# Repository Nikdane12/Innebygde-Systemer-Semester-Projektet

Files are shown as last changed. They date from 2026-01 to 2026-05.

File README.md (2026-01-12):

# Innebygde-Systemer-Semester-Projektet
## Sjekkliste
1. Complete the plan of record (POR).
2. Complete the preliminary bill of materials (BOM).
3. Complete the final schematic capture and final BOM.
4. Complete the board layout and order all the parts.
5. Complete the assembly.
6. Complete the bring up, troubleshoot, and final test.
7. Complete the documentation
## POR
- [ ] Visualiser hele prosjeketet før det startes
- [ ] Risikovurdering og risikobegrensing
- [ ] Overordnet beskrivelse av prosjektet, og hva som skal fungere
- [ ] POR er et levende dokument som oppdateres når det kan.
- [ ] Tenk på hva som i verste fall kan skje for hvert steg.
- [ ] Unngå feature creep i denne fasen *
- [ ] Estimer det du kan: lab budsjett for strøm pris og leveringstider
- [ ] BOM for de mest kritiske komponentene
- [ ] Gjør en risikoanalyse, og lag plan B-C osv. For potensielle problemer.
## Prosjekt Idèer
- [ ] Spill som bruker ulike sensorer
- [x] Temperatur og fukt-regulert brøddeigboks
- [ ] Drinkmikser
- [ ] Batteridreven bakkestasjon
- [ ] IR-fjernkontroll med vinkelstyring
- [ ] UI for underviser-student-kommunikasjon
- [x] Alternativ navigasjonsmetode for droner
- [ ] Tilgangssystem til dør
- [x] Utskytningsrampe for fixed-wing-drone
- [ ] Plantevannesystem
- [ ] Styring til kaffemaskin
- [ ] Vannkraftverk-modell
- [x] Kamera som følger et objekt
- [x] Globalt posisjoneringssystem med teleskop
- [x] Arm drink dispenser
- [x] Self-leveling table
- [ ] auto solder dispenser

kamera
uv detektor
supersonic sensor
predefined
    vekt/trykk sensor
        mål drikke vekt
    magnetsensor
    lyssensor

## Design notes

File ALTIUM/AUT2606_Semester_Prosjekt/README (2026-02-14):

# README – Kretskort for robotarm (væskefylling)

## 1. Kort beskrivelse
Dette kretskortet er en del av et system for en **robotarm som kan navigere til predefinerte posisjoner og fylle glass med væske**.  
Kortet brukes som grensesnitt mellom Raspberry Pi, servoer, pumpe og sensorer, og muliggjør styring samt innhenting av måledata.

---

## 2. Systemfunksjon
Systemet skal:
- Styre flere servoer synkronisert
- Styre en pumpe som leverer væske i kontrollerte mengder
- Måle vekt ved hjelp av loadcell for å avgjøre når et glass trenger påfyll
- Kommunisere med Raspberry Pi via I²C og digitale signaler

---

## 3. Grunnlinjefunksjonalitet
- Robotarmen kan bevege seg til en forhåndsdefinert posisjon  
- Servoene beveger seg koordinert og jevnt  
- Pumpen leverer en repeterbar mengde væske  
- Systemet kan avgjøre når et glass trenger mer væske basert på vekt  

### Ønsket ekstrafunksjonalitet
- Kamera for økt presisjon (ikke implementert på dette kretskortet)

---

## 4. Kretskortets rolle
Kretskortet fungerer som et **styre- og grensesnittkort** mellom Raspberry Pi og følgende moduler:
- PWM-servo-driver (PCA9685)
- Vektsensor-forsterker (HX711)
- Ekstern pumpe-driver (TC1508-modul)

---

## 5. Komponenter (BOM – oversikt)
Viktige komponenter på kretskortet:
- **HX711** – ADC/forsterker for loadcell
- **Loadcell 1 kg** – Vektmåling
- **Servo-tilkoblinger** – 3 kraftservoer + 1 mikroservo
- **Pumpe-tilkobling** – Styring via ekstern H-bridge

### Standard / No BOM

- HX711
- PCA9685
- Loadcells
- Servo motorer
- Pumpe

---

## 6. Multiplisitet
- Det bestilles 2 kort (Hoved og HX711)
- Alle komponentantall i BOM er oppgitt

---

## 7. PCB- og mekaniske begrensninger
- Maks størrelse: **60 mm × 30 mm**
- 2-lags PCB
- Kompatibel med **JLCPCB design rules**
- Hovedsakelig SMD-komponenter på **Top Layer**
- Testpunkter, tydelig silketrykk og innfesting er inkludert der det er relevant

---

## 8. Bring-up (kortversjon)
1. Verifiser I²C-kommunikasjon mellom Raspberry Pi og PCA9685  
2. Test styring av én servo  
3. Test HX711 med last på loadcell  
4. Test start/stopp av pumpe  
5. Integrer vektmåling og pumpe i lukket sløyfe  

---

## 9. Designerinformasjon
**Navn:** Nikolai A. Dickens  
**Kontakt:** nidic4105@uit.no

**Navn:** Olav A. Sødal  
**Kontakt:** olsod5888@uit.no

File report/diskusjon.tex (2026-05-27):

\section{Diskusjon}
Resultatene viser at systemet fungerte etter hensikten. Armen klarte å registrere når en kopp kom under den gitte terskelverdien, bevege seg til riktig posisjon og fylle koppen til eller over målnivået.

Som nevnt i resultatene var det et avvik under fylleprosessen. Avviket vurderes som akseptabelt for fylling av et glass, men kan reduseres ved å forbedre målingene fra loadcellene. En feilkilde her var drift i verdiene fra HX711, der avlesningene endret seg gradvis over tid uten endring i vekt. Denne driften er en av årsakene til det varierende avviket etter fylling. Effekten av driften kan reduseres ved jevnlig nullstilling (tare), filtrering av avlesningene gjennom median- eller gjennomsnittsmodus, og bedre skjerming av kabler for å redusere støy.

At reguleringen fungerte tilfredsstillende med så lite tuning av PID-verdiene tyder på at de valgte standardverdiene var godt egnet for systemet.
 
Likevel, selv om systemet nådde hensikten, var det noen svakheter og feilkilder i dette systemet.

En mekanisk svakhet var at de interne tannhjulene i servoene var laget av plast. Som beskrevet i resultatene førte dette til at servoen på skulderen sluttet å rotere etter høyt stress. Årsaken er at servoene som ble brukt ikke er dimensjonert for de kreftene armen utsettes for, noe som er en kjent svakhet ved billigere servoer med plastgir. Bytte til en servomotor med metallgir løste problemet, og er også å foretrekke på lengre sikt for å sikre armens presisjon og levetid. 

Problemet med ''brownout'' på RPi-en skyldtes ikke selve strømforsyningen, men ledningene mellom strømforsyningen og hoved-PCB-en. Opprinnelig var det brukt tynne kabler som var ''daisychained'' videre til kortet, noe som ga for stort spenningsfall ved høyt strømtrekk, særlig når servoene og pumpen var aktive samtidig. En ''brownout'' kan føre til ustabil oppførsel eller at Pi-en restarter. Problemet ble løst ved å bytte til kraftigere kabler koblet direkte fra strømforsyningen til hoved-PCB-en. Dette reduserte spenningsfallet, og strømforsyningen leverte deretter stabil spenning også under høy belastning.

De tre feilene som ble oppdaget på hoved-IO-kortet lot seg fikse med loddebroer og kabling, og bør rettes opp i designet i en eventuell ny revisjon av kortet.

Noen tekniske valg ble gjort under dette prosjektet. Det ble valgt å bruke en egen PSU i stedet for en laboratorie strømforsyningen. Dette var fordi at systemet hadde behov for en strømforsyning som kunne levere nok amper til alle komponentene samtidig (kan se i POR-vedlegget). Det som er beskrevet over viste det seg likevel at strømforsyningen ikke var godt nok dimensjonert noe som førte til ''brownout'' ved høyt strømtrekk. Varselmeldingen på RPi-en om at det var for lite strøm kan være fordi PSU-en leverte 4,9V i stedet for 5V eller helst 5,1 V til RPi-en. Dette valget bør derfor revurderes med tanke på en annen PSU.

For å styre pumpen med PWM-signaler ble det valgt å bruke en ekstern modul (L298N) i stedet for å integrere H-broen direkte på PCB-en. Dette var fordi det begynte å bli lite plass igjen på PCB-en til alle funksjonene, og for å redusere risikoen for at hovedfunksjonen: å styre pumpen med PWM, ikke skulle fungere. Ved å legge pumpestyringen i en egen modul ble designet enklere og sjansen for feil på selve kortet redusert.

Samlet sett fungerte systemet etter hensikten. Pumpestyringen med PID-regulering ga presis fylling med kun et lite avvik, og robotarmen klarte å bevege seg mellom de forhåndsdefinerte posisjonene som planlagt. Svakhetene som ble avdekket lot seg alle utbedre underveis, og påvirket ikke det endelige resultatet.

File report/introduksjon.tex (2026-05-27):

\section{Introduksjon}
I dette semesterprosjektet har vi laget en automatisk refill-arm, en robotarm som fyller glass med væske når en vektsensor registrerer at de er tomme. Prosjektet er gjennomført i emnet AUT-2606 ved Institutt for Automasjon og Prosessteknologi, og målet har vært å vise og videreutvikle vår kunnskap innen mekanismer, PCB-design og programmering.

Rapporten gir først en gjennomgang av det teoretiske grunnlaget for komponentene og metodene som er brukt, blant annet regulering og invers kinematikk. Deretter beskrives metodikken bak design av kretsen, lodding og programvaren, før vi presenterer og diskuterer resultatene fra det ferdige systemet.

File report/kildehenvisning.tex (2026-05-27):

\section{Kildehenvisning}
\begin{hangparas}{0.5in}{1}
Cults3D. (u.å.). \emph{Arduino based robot arm – HowToMechatronics} [3D-modell]. Hentet 26. mai 2026 fra \url{https://cults3d.com/en/3d-model/various/arduino-based-robot-arm-howtomechatronics}

Handson Technology. (u.å.). \emph{L298N dual H-bridge motor driver} [Datablad]. Hentet 26. mai 2026 fra \url{https://www.handsontec.com/dataspecs/L298N\%20Motor\%20Driver.pdf}

NXP Semiconductors. (2015). \emph{PCA9685: 16-channel, 12-bit PWM Fm+ I\textsuperscript{2}C-bus LED controller} [Datablad]. \url{https://www.nxp.com/docs/en/data-sheet/PCA9685.pdf}

SparkFun Electronics. (u.å.). \emph{HX711: 24-bit analog-to-digital converter (ADC) for weigh scales} [Datablad]. Hentet 26. mai 2026 fra \url{https://cdn.sparkfun.com/datasheets/Sensors/ForceFlex/hx711_english.pdf}

Wikipedia. (u.å.). \emph{Inverse kinematics}. Hentet 26. mai 2026 fra \url{https://en.wikipedia.org/wiki/Inverse_kinematics}

[Forfatter, A. A.]. (årstall). \emph{Inverse kinematics} [Figur]. ResearchGate. \url{https://www.researchgate.net/figure/Inverse-kinematics-problem-of-3-DOF-robot-arm-in-2D-plane-a-Three-joints-and-an_fig3_46401997}

[Forfatter, A. A.]. (årstall). \emph{Inverse kinematics}. ResearchGate. \url{https://www.researchgate.net/publication/274164740_Inverse_Kinematics}
\end{hangparas}

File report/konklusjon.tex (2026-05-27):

\section{Konklusjon}
I dette prosjektet ble det laget en automatisk refill arm som fyller glass med væske når en vektsensor registrerer at de er tomme. Systemet ble bygget opp av en Raspberry Pi med egendesignede PCB-er, 3D-printede deler og øvrige elektronikkomponenter, og programvare som håndterer PID-regulering og invers kinematikk.

Prosjektet nådde hovedmålet sitt. Den ferdige armen klarte å registrere tomme kopper og bevege seg til riktig posisjon og fylle dem med et avvik på omtrent 10g som blir vurdert som tilstrekkelig presist for formålet. 

For videre arbeid bør de tre feilene som ble oppdaget under testing: manglende jording av OE-pinnen på PCA9685, ombyttede I2C-pinner, og manglende styringspinne for pumpen, rettes direkte i designet i en ny revisjon av kortet, slik at de ikke lenger må utbedres med loddebroer og kabling. Videre bør servoene byttes ut med motorer med metallgir i stedet for plastgir for å gjøre armen mer robust. På lengre sikt kan systemet integreres med trådløs kommunikasjon mellom lastcellene og RPi-en, noe som ville gjort oppsettet mer fleksibelt og redusert behovet for kabling.

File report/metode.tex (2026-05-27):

\section{Metode}
\begin{figure}[H]
    \centering
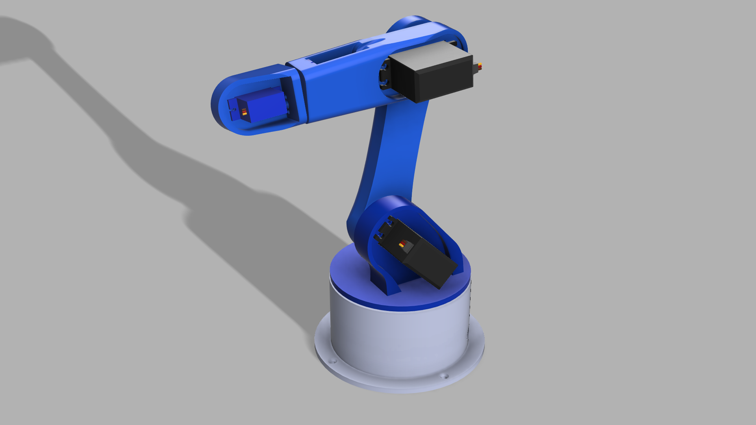
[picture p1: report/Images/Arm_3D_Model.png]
    
    \caption{3D model av robot arm}
    \label{fig:3D_arm}
\end{figure}

\subsection{Testing før mottatt PCB}
Siden produksjon og levering av PCB-ene tok tid, var det viktig å verifisere at de sentrale komponentene og kommunikasjonsprotokollene fungerte før kortene kom i posten. Raspberry Pi-en ble stilt til rådighet av universitetet tidlig i prosjektet, og vi brukte derfor denne til å teste de ulike delene av systemet hver for seg på forhånd.

Først testet vi I2C-kommunikasjonen, ettersom denne er avgjørende for styringen av servomotorene. Ved hjelp av en frittstående PCA9685-modul koblet til Raspberry Pi-en kunne vi bekrefte at Pi-en oppdaget enheten på I2C-bussen, og at vi klarte å generere stabile PWM-signaler ut fra modulen. På denne måten fikk vi verifisert både selve I2C-oppsettet og at vi kunne styre en servomotor via PCA9685 før dette ble integrert på vårt eget kort.

\subsection{Kretsen}
Vi tok hva vi hadde i POR-en for å finne ut hvilke funksjoner som var nødvendige, og hvilke som kunne inkluderes om vi hadde plass til det. Vi fant ut at kortet skal gi ut fem PWM-signaler, tre knapper, muligheten strømtilførsel uten USB-C, fire ledige pins for I2C-kommunikasjon, samt tre HX711-brikker for loadcells.

\input{BOM}

Ved bruk av Raspberry Pi-en ble hovedprosesseringen og styringen forenklet. Pi-en ga en fornuftig måte å kommunisere med de andre komponentene på, via I2C, bit-banging og innlesing gjennom GPIO-pinnene.

Først fant vi ut hvordan PWM-utgangene skulle styres. PWM-signalet genereres ikke direkte av Raspberry Pi-en, men av en PCA9685 PWM-driver som Pi-en kommuniserer med over I2C. Figur \ref{fig:transistor} viser hvordan transistoren brukes. Signalet fra PCA chippen føres til PWM inngangen i kretsen, der strømmen går gjennom en motstand som begrenser basestrømmen til transistoren. Transistoren er en NPN BJT som opererer i en «common-emitter»-konfigurasjon, det vil si at emitteren er felles for inngangen og utgangen. Deretter er collector-pinnen koblet til en pull-up-motstand.

Når PWM-signalet er høyt, driver basestrømmen transistoren til saturation. Collectoren blir da trukket ned mot GND, og utgangen settes lav. Når PWM-signalet er lavt, går det ingen strøm til basen, og transistoren er «av». Da går det ingen strøm gjennom pull-up-motstanden, og utgangen trekkes høy til 5V.

\begin{figure}[H]
    \centering
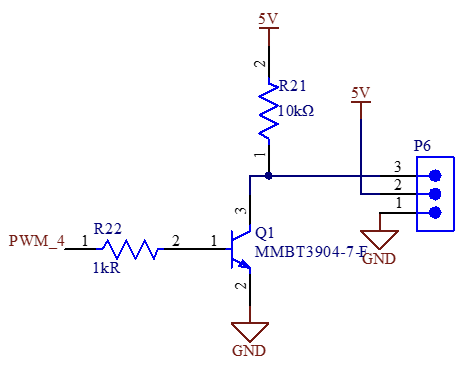
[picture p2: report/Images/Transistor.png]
    
    \caption{Transistor oppsett}
    \label{fig:transistor}
\end{figure}

Hx711 kretsen var en ukjent komponent som krevet mye forskning. Hoved krets design/oppsett kom fra en produsent som leverer ferdig bygget Hx711 PCB-er. 

\subsection{Beste praksis for PCB-design}
\textbf{Avkoblingskondensatorer:} Hver aktive komponent ble utstyrt med avkoblingskondensatorer plassert så nær forsyningspinnene som mulig. PCA9685 og HX711-brikkene har dedikerte 100nF keramiske kondensatorer for å filtrere ut høyfrekvent støy, samt større 10 µF elektrolytt-/keramiske kondensatorer for å stabilisere forsyningsspenningen ved raske lastendringer. 

\textbf{Jordplan:} Kortet ble lagt ut med et sammenhengende jordplan (kobberfyll for GND). Et jordplan gir lav impedans tilbake til forsyningen og korte returbaner for signalstrømmene, noe som reduserer støy og gir mer stabile referansenivåer. Dette er særlig fordelaktig for de analoge målesignalene fra lastcellene, der et stabilt jordreferansenivå er avgjørende for nøyaktige avlesninger.

\textbf{Sporbredde for forsyning:} Spor som fører forsyningsstrøm (5V og 12V) ble tegnet merkbart bredere enn signalspor. Bredere spor har lavere resistans, noe som reduserer spenningsfallet og varmeutviklingen ved høyt strømtrekk. Dette er viktig i et system der servoer og pumpe kan trekke betydelig strøm samtidig.

\textbf{Separasjon av analoge signaler:} De analoge linjene fra lastcellene ble bevisst holdt adskilt fra PWM- og effektspor. Ved å unngå at følsomme målesignaler rutes parallelt med eller krysser støyende spor, reduseres innkobling av støy på HX711-avlesningene.

\subsection{Lodding}
    \hl{plassering av komponenter\\
    varmeovn\\
    through-hole deler}
\subsubsection{Enderinger}
    \hl{SDA pin\\
    floating ground\\
    pumpe int pin}

\subsection{Programmering}
\subsubsection{PCA9685}
PCA9685 chippen kommuniserer gjennom I2C, og siden PCA9685 er en ganske populær chip som blir brukt for å klare å styre flere servo motorer samtidig så eksisterte det allerede et bibliotek på python for denne chippen.

\subsubsection{HX711}
HX711 bruker sin egen type protokoll for kommunikasjon. Hvor RPi-en sender en 24 klokke pulser og for hver puls sender chippen ut et bit. Fra dette kan vi få data ut fra loadcellene som kan tolkes til vekt.

\subsection{main.py}
Programmet består av tre hoveddeler: import av nødvendige biblioteker, 
definisjon av matematiske funksjoner, og bygging av grafisk brukergrensesnitt (GUI).

\begin{figure}[H]
    \centering
    \includesvg[width=.75\linewidth]{Images/PackageDiagram.svg}
    \caption{Package Diagram}
    \label{fig:PackageDiagram}
\end{figure}

\subsubsection{Importerte biblioteker}
Følgende biblioteker blir importert:
\begin{itemize}
    \item \texttt{tkinter} — brukes til å lage det grafiske brukergrensesnittet (GUI)
    \item \texttt{time} — brukes til tidsmåling i PID-regulatoren
    \item \texttt{subprocess} — brukes til å starte eksterne prosesser, 
          som benchmark-programmet
    \item \texttt{math} — brukes til trigonometriske beregninger i invers kinematikk
    \item \texttt{ADAfruit} — 
    \item \texttt{hx711} — egen modul for avlesning av vektceller
\end{itemize}

\subsubsection{Tilstand}
Programmet bruker en global tilstandsmaskin med tre tilstander for fylleprosessen:
\begin{itemize}
    \item \texttt{idle} — systemet venter og overvåker vektcellene
    \item \texttt{moving} — armen beveger seg mot riktig glass
    \item \texttt{filling} — pumpen er aktiv og PID-regulatoren styrer fyllingen
\end{itemize}

\begin{figure}[H]
    \centering
    \includesvg[width=.75\linewidth]{Images/Tilstandsdiagram.svg}
    \caption{Tilstands Diagram}
    \label{fig:Tilstandsdiagram}
\end{figure}

\subsubsection{Invers kinematikk}
Funksjonen \texttt{solve\_ik()} beregner leddvinklene som kreves for å 
plassere endeffektoren i en gitt posisjon $(x, y, z)$ med ønsket 
orientasjon $\phi$.

\subsubsection{PID-regulator}
Funksjonen \texttt{pid\_control()} implementerer den diskrete PID-regulatoren. Regulatoren styrer pumpeeffekten 
basert på differansen mellom ønsket fyllingsnivå og målt vekt. 
Standardverdiene er satt til:
\begin{itemize}
    \item $K_p = 0.5$
    \item $K_i = 0.1$
    \item $K_d = 0.05$
\end{itemize}
Disse kan justeres direkte i GUI-et under kjøring.

\subsubsection{Fylleprosess}
Fylleprosessen styres av tre funksjoner:
\begin{itemize}
    \item \texttt{start\_fill()} — flytter armen til riktig glass og starter pumpen
    \item \texttt{begin\_pump()} — aktiverer pumpen og nullstiller PID-tilstanden
    \item \texttt{pid\_fill\_loop()} — kjører PID-regulatoren i en løkke med 
          \texttt{PID\_POLL\_MS} intervall (standard 200~ms) til målvekten er nådd
    \item \texttt{stop\_pump()} — slår av pumpen og returnerer til \texttt{idle}
\end{itemize}

Hvis vektcellen leser en negativ verdi under fylling tolkes dette som at 
glasset er løftet bort, og fyllingen avbrytes automatisk.

\subsubsection{Hovedløkke}
Funksjonen \texttt{main\_loop()} kjøres hvert 500~ms og overvåker alle 
tre vektcellene. Hvis systemet er aktivert og et glass er under 
terskelverdien \texttt{FILL\_THRESHOLD\_G} (standard 150~g), 
startes fylleprosessen automatisk for det aktuelle glasset.

\subsubsection{GUI}
GUI-et er bygget med \texttt{tkinter} og inneholder følgende seksjoner:
\begin{itemize}
    \item \textbf{Joint Control} — glidere for manuell styring av hvert ledd 
          (midje, skulder, albue, wrist) samt pumpe
    \item \textbf{Inverse Kinematics} — inntastingsfelt for målposisjon 
          $(x, y, z, \phi)$ og geometriparametere
    \item \textbf{Saved Positions} — lagring og avspilling av inntil 3 posisjoner med jevn interpolasjon
    \item \textbf{Load Cell} — sanntidsavlesning av alle tre vektceller med valg mellom live- og medianmodus
    \item \textbf{Tare og Kalibrering} — Kalibrering av innsamlet data fra loadcells og nullstillingsfunksjon
    \item \textbf{Fill Settings} — innstilling av terskel- og målvekt for fylling
    \item \textbf{Water Level} — fremdriftsindikatorer som viser fyllingsnivå 
          for hvert glass
    \item \textbf{PID Controller} — felt for $K_p$, $K_i$ og $K_d$ 
          med knapp for å anvende nye verdier under kjøring
\end{itemize}

\subsubsection{Avslutning}
Når programmet avsluttes frigjøres alle ressurser:
\begin{itemize}
    \item Vektcellene \texttt{sensor1}, \texttt{sensor2}, \texttt{sensor3} lukkes
    \item SPI-klokken \texttt{hx711.sck} lukkes
    \item Pumpe-GPIO-porten \texttt{pump\_fwd} lukkes
    \item I2C-bussen \texttt{i2c.bus} lukkes
\end{itemize}

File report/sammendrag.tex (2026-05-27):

\section{Sammendrag}
Vi har satt oss fore å lage en maskin som viser vår kunnskap om mekanismer, PCB-design og programmering. Hovedsystemet er satt sammen av en Raspberry Pi, tilpassede PCB-er, 3D-printede deler og andre elektronikkomponenter. Vi har tilpasset alle komponenter slik at de passer sammen, og designet PCB-ene for å levere den nødvendige funksjonaliteten: PWM-utganger, I/O-knapper, HX711 loadcell-brikker og dedikerte I2C-tilkoblinger. Programvaren gir PID-regulering, IK-posisjonering og tilstandsmaskiner. Til slutt har vi bygget, testet, feilrettet og ferdigstilt en robotarm som fyller glass når vektsensoren registrerer at de er tomme. Vi har dermed nådd målet for semesterprosjektet.

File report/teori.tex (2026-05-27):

\section{Teori}

\subsection{Raspberry Pi}
Raspberry Pi er datamaskinen i dette prosjektet. Det ble valgt for å bruke RPi fordi det er en kraftig datamaskin som kan kjøre programmer raskt, samtidig som den har GPIO-pinner som gir mulighet for tilkobling av ekstern tilkobling. RPi-en kan også kobles til GitHub, noe som gir en raskere og enklere arbeidsflyt. I tillegg støtter RPi-en alle kommunikasjonsprotokollene vi trengte i prosjektet, blant annet I2C og bit bang.

\subsection{PCA9685}
For å kunne kontrollere flere servomotorer samtidig ved bruk av RPi-en, brukte man chippen PCA9685. Denne gjør det mulig å styre opptil 16 servomotorer via I2C, med presise og stabile PWM signaler enn hva RPi-en kan gi.

\subsubsection{I2C}
I2C er kommunikasjon protokollen som blir brukt i PCA9685. I2C blir vanligvis brukt å koble mellom mikrokontrollere og sensorer, minnebrikker og andre enheter. 

Buss strukturen til I2C er en synkron toveis kommunikasjonsbuss som kun benytter av to ledere: SDA (Serial Data) som er linjen som overfører data og SCL (Serial Clock) som er klokken som synkroniserer dataoverføringen laget av master enheten.

Kommunikasjonen bruker master og slave prinspit. Det er en master enhet (vanligvis en mikrokontoler eller RPi i dette prosjektet) som styrer klokkesignalet og initialerer komunaksjonen. Og slave enheter svarer når kun de er addresert. Man kan tenke seg slikk at master enheten er posten som levere ut inviasjonen og slaven kan bare svare hvis de har fått invitasjoner. Hver slave har en unik addresse som er regel på 7 bit. Det gir i teori opp til 128 enheter på samme buss linje.

\colorbox{yellow}{placeholder}
Data overføring skjer slik ut. 
Masteren sender en startbetingelse (SDA går lav mens SCL er høy).
Masteren sender slavens 7-bits adresse fulgt av en lese-/skrivebit (R/ som angir overføringsretning.
Den adresserte slaven svarer med et ACK-bit (acknowledge) for å bekrefte at den er tilstede.
Data overføres byte for byte, hvor hver byte etterfølges av et ACK- eller NACK-bit fra mottakeren.
Masteren avslutter med en stoppbetingelse (SDA går høy mens SCL er høy).

\subsection{HX711}
For å måle vekten på glassene brukte vi chippen HX711. Denne chippen leser av analoge signaler fra en lastcelle og konverterer dem til digitale data. HX711 er en 24 bits analog til digital omformer (ADC) spesielt beregnet for lastceller. Chippen kommuniserer med RPi-en via sin egen serielle protokoll basert på bit-banging. Siden hver HX711 kun kan lese fra en lastcelle, måtte vi ta i bruk tre chipper for å kunne lese av tre lastceller.

\subsubsection{Bit bang}

\subsection{Dual H-Brigde L298N module}
Modulen bruker både 5V og 12V. Den mottar et PWM-signal og har i tillegg en «HIGH-pin» og en «LOW-pin» som bestemmer hvilken retning pumpen går. Bytter man om på disse to pinnene, snur pumpe retningen.

Modulen er en dobbel bidireksjonell H-bro. Det betyr at den kan styre to DC-motorer samtidig uavhengig av hverandre. En H-bro er en standard-krets av fire transistorer satt sammen i en form som ligner på bokstaven H, hvor motoren er plassert i midten. Med å aktivere diagonalt motsatte transistorer kan strømmen gå gjennom motoren, og å aktivere motsatte transistorer vil de gå motsatt vei.

PWM-signalet brukes til å styre hastigheten på motoren. PWM-en veksler raskt mellom «HIGH» og «LOW», og forholdet mellom "HIGH" tid og "LOW" tid kalles «duty cycle». En høy duty cycle gir motoren høyere hastighet, mens en lav duty cycle gir lavere hastighet.

\subsection{Regulering}
For å fylle glasset og sikre at det blir fylt opp uten søl, brukes en form for regulering. En regulator sin oppgave er å styre et system slik at den målte $y(t)$ følger en ønsket referanseverdi så presist som mulig. I dette prosjektet styres pumpen ut fra hvor mye væske som skal være i glasset, slik at fyllingen stoppes på riktig tidspunkt.

\begin{figure}[H]
    \centering
    \includesvg[width=1\linewidth]{Images/PID.svg}
    \caption{PID sløyfe}
    \label{fig:PID_diagram}
\end{figure}

Reguleringen er bygget opp som en \emph{lukket sløyfe}. Det innebærer at den målte $y(t)$ kontinuerlig sammenlignes med referanseverdien, og at differansen mellom dem brukes til å bestemme pådraget. Feilsignalet er definert som differansen mellom referanseverdien $y_0(t)$ og målte ut verdien $y(t)$:
\begin{equation}
    e(t) = y_0(t) - y(t)
\end{equation}

Uten PID følger kontrolleren en på/av-logikk:
\begin{equation}
    u(t) = \begin{cases} 1 & \text{hvis } e(t) > 0 \\ 0 & \text{hvis } e(t) \leq 0 \end{cases}
\end{equation}

For å oppnå en jevnere og mer presis styring brukes en PID regulator. PID regulatoren består av: et proporsjonalt ledd (P), et integrasjoins ledd (I) og et deriverende ledd (D). 

Og under er $K_p$, $K_i$ og $K_d$ forsterkningskonstantene for henholdsvis proporsjonal, integral og derivasjons leddet. Disse må tunes inn for å gi ønsket oppførsel, der målet er en rask respons med lite oversving og liten stasjonær feil og unngå oscillasjon.
\begin{equation}
    u(t) = K_p \cdot e(t) + K_i \int_0^t e(\tau)\,d\tau + K_d \frac{de(t)}{dt}
\end{equation}

Den diskrete formelen som brukes i koden er:
\begin{equation}
    u[k] = K_p \cdot e[k] + K_i \sum_{j=0}^{k} e[j] \cdot \Delta t + K_d \frac{e[k]-e[k-1]}{\Delta t}
\end{equation}

Integralleddet er her tilnærmet med en Riemann sum, der feilen i hvert tidssteg multipliseres med $\Delta t$ og summeres opp. Derivasjonsleddet er tilnærmet med baklengs differanse (finite difference), altså endringen i feilsignalet fra forrige til nåværende tidssteg delt på $\Delta t$. Disse tilnærmingene blir mer nøyaktige jo mindre $\Delta t$ er.

\subsection{Invers kinematikk}
For å styre bevegelsen til robotarmen brukte vi en forenklet versjon av invers kinematikk. Vi valgte invers kinematikk fremfor fremoverkinematikk fordi fremoverkinematikk beregner endepunktet ut fra kjente leddvinkler, mens invers kinematikk gjør det motsatte den beregner nødvendige leddvinkler for å oppnå en ønsket endeposisjon. Robotarmens geometri er illustrert i figur \ref{fig:3dof}.

\begin{figure}[H]
    \centering
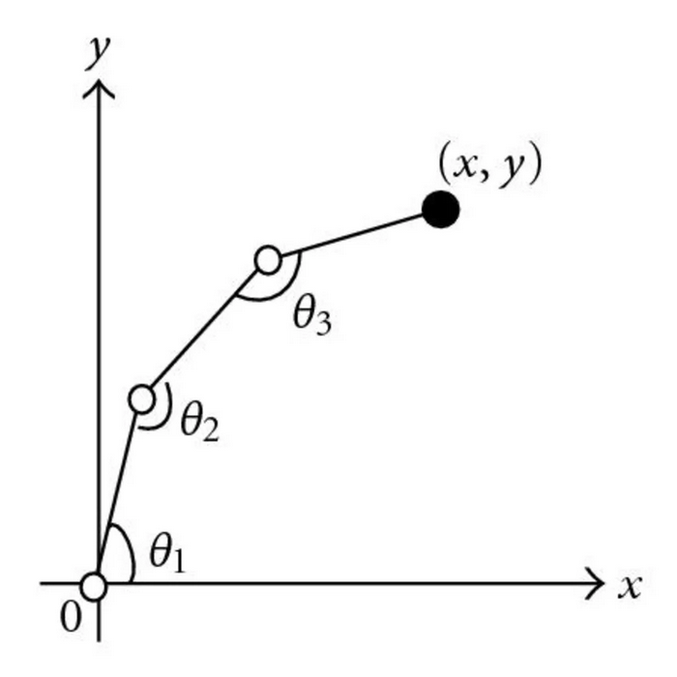
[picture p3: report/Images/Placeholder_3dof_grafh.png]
    
    \caption{Diagram over robotarmens geometri med tre frihetsgrader.}
    \label{fig:3dof}
\end{figure}

Vi definerer håndleddspunktet $(x_w, y_w)$ ved å trekke fra bidraget fra det siste leddet med lengde $L_3$:
\begin{align}
    x_w &= x - L_3 \cos(\varphi) \\
    y_w &= y - L_3 \sin(\varphi)
\end{align}
Vinkelen $\theta_2$ finnes ved hjelp av cosinussetningen:
\begin{align}
    \cos(\theta_2) &= \frac{x_w^2 + y_w^2 - L_1^2 - L_2^2}{2 L_1 L_2} \\
    \theta_2 &= \text{atan2}\!\left(\pm\sqrt{1 - \cos^2(\theta_2)},\ \cos(\theta_2)\right)
\end{align}
Deretter beregnes $\theta_1$ og $\theta_3$:
\begin{align}
    \theta_1 &= \text{atan2}(y_w,\ x_w) - \text{atan2}(L_2 \sin(\theta_2),\ L_1 + L_2 \cos(\theta_2)) \\
    \theta_3 &= \varphi - \theta_1 - \theta_2
\end{align}

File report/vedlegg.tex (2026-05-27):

\section{Vedlegg}

\begin{figure}[H]
    \centering
    \includesvg[width=.75\linewidth]{Images/DeploymentDiagram.svg}
    \caption{Deployment Diagram}
    \label{fig:DeploymentDiagram}
\end{figure}

\begin{figure}[H]
    \centering
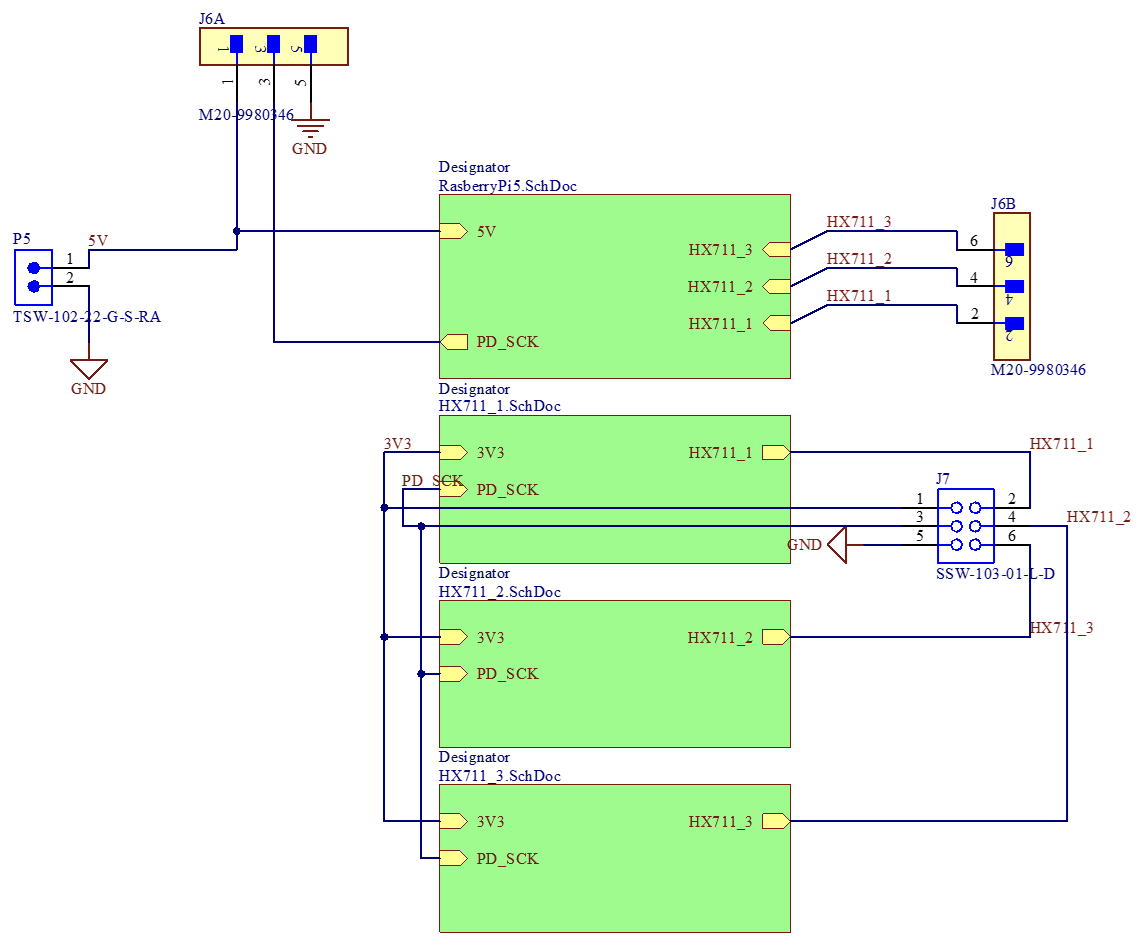
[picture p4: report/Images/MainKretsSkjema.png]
    
    \caption{Hoved kretskjema der alle individe komponenter ble satt sammen.}
    \label{fig:hovedkrets}
\end{figure}

\begin{figure}[H]
    \centering
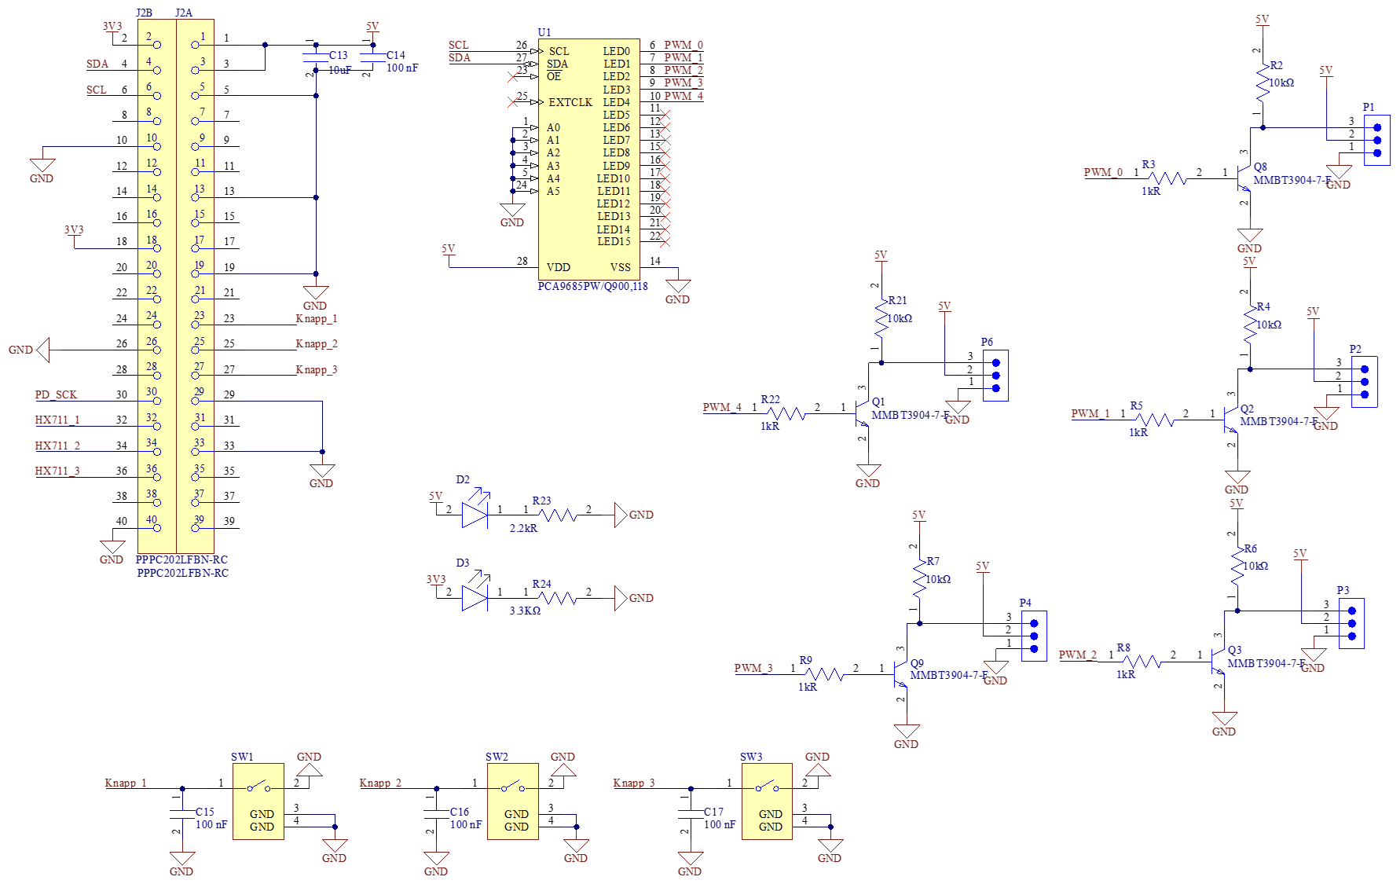
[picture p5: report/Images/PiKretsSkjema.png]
    
    \caption{Pi interface som inkludere PCA9685, PWM switchers, og knapper}
    \label{fig:pikrets}
\end{figure}

\begin{figure}[H]
    \centering
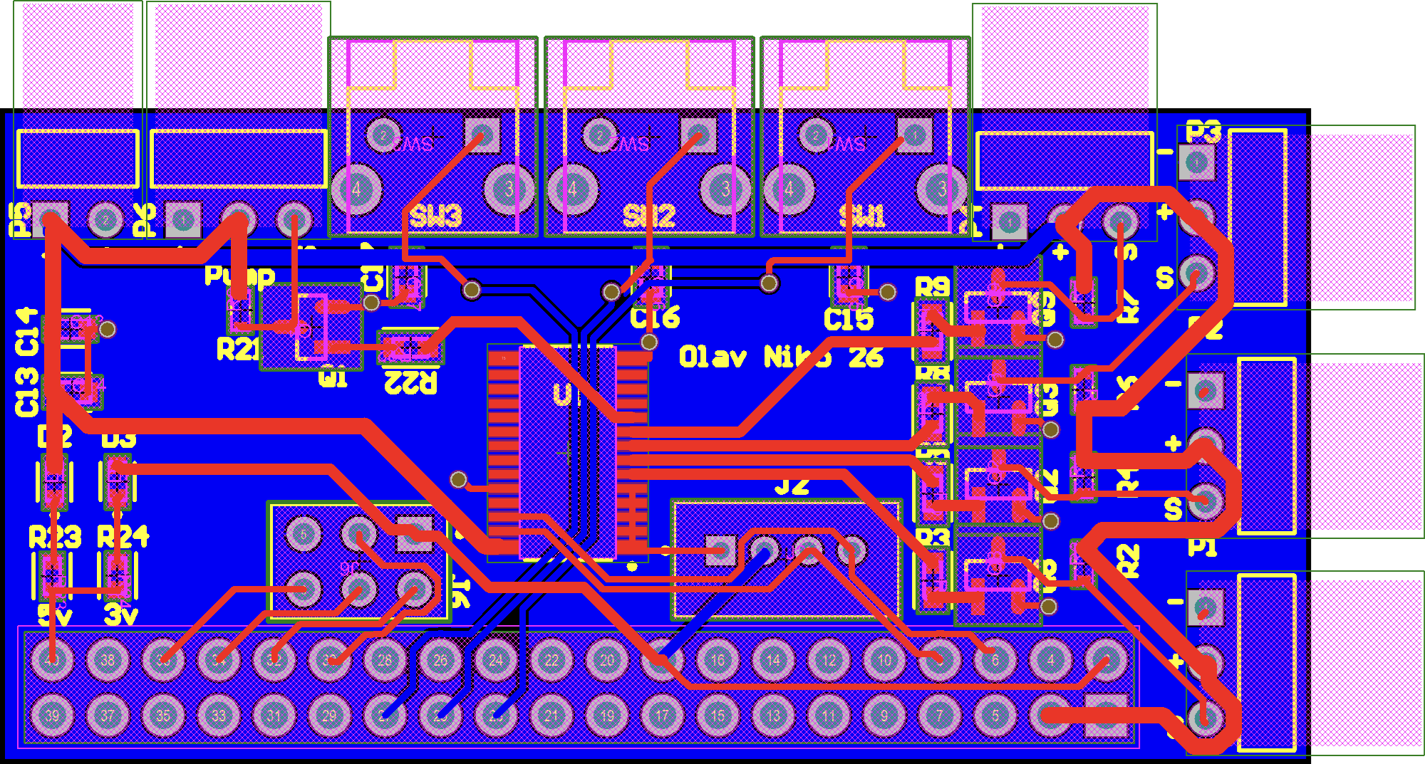
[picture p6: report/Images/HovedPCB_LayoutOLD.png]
    
    \caption{Hoved PCB}
    \label{fig:Hoved PCB}
\end{figure}

\begin{figure}[H]
    \centering
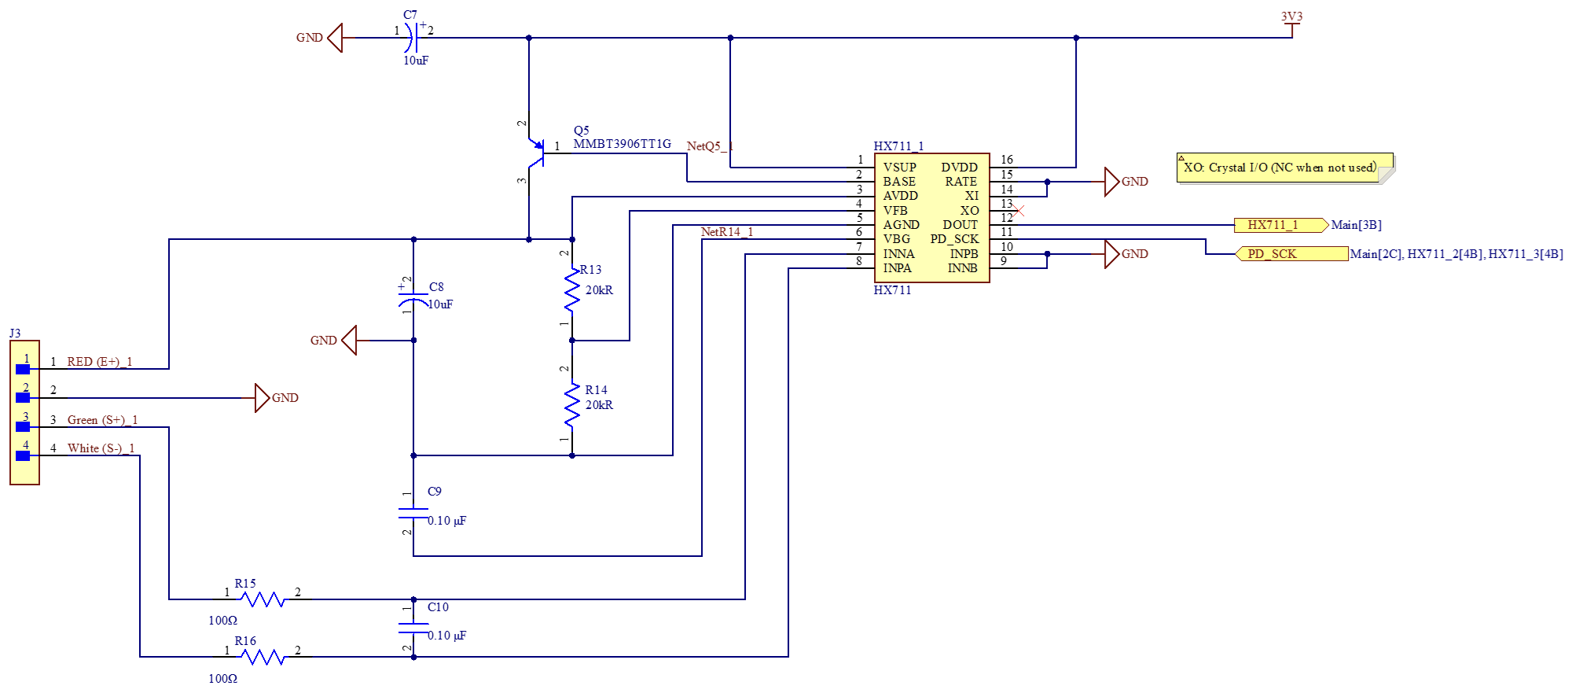
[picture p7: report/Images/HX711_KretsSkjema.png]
    
    \caption{Individ Hx711 krets}
    \label{fig:hx711krets}
\end{figure}

\begin{figure}[H]
    \centering
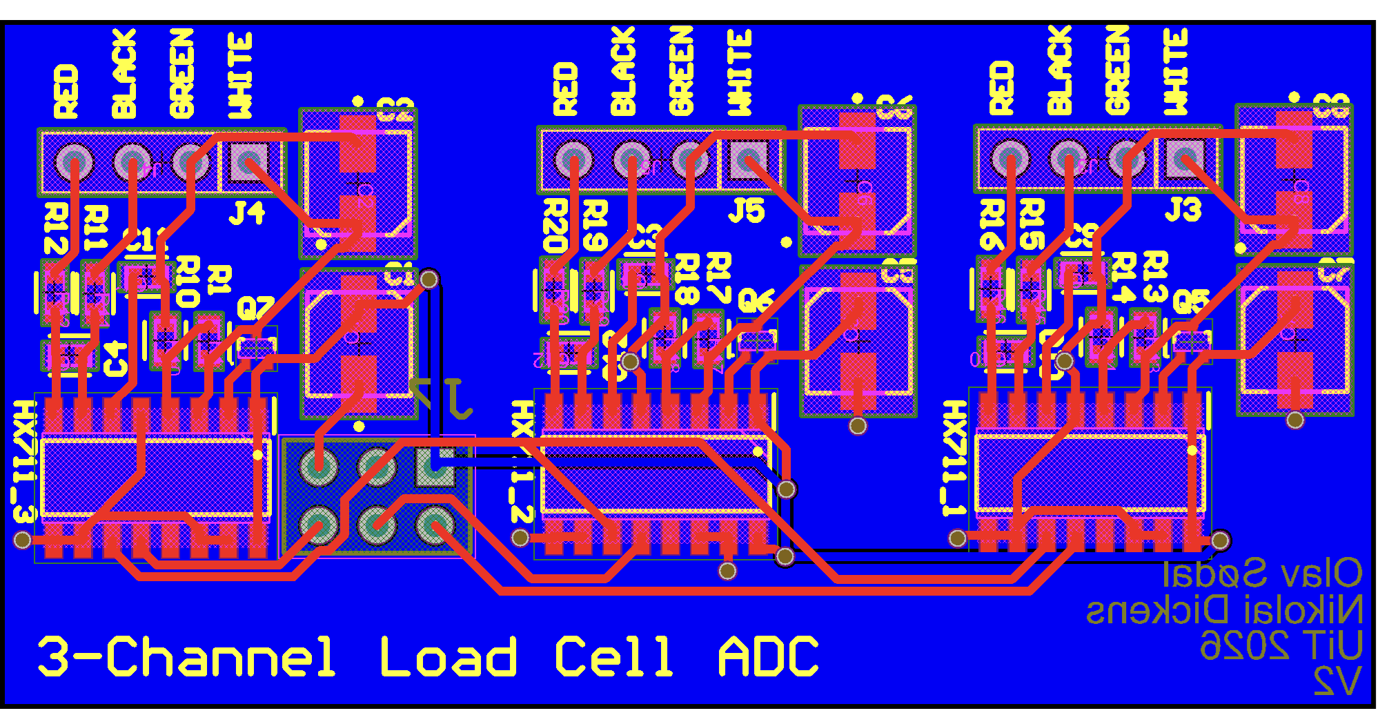
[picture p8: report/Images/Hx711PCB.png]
    
    \caption{HX711 PCB}
    \label{fig:Hx711PCB}
\end{figure}

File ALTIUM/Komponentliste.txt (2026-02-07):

6V servo: https://www.pololu.com/file/0J730/HD-6001HB.pdf
Loadcell: https://www.electrokit.com/upload/quick/e8/9b/da2b_41032778-tds.pdf, Converter https://cdn.sparkfun.com/datasheets/Sensors/ForceFlex/hx711_english.pdf
Pumpe: https://www.electrokit.com/vattenpump-12v

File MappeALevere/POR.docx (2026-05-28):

Plan of Record (oversikt)

- Funksjonen til kortet/systemet er tydelig forklart
- For å unngå feature creep, tydeliggjør en grunnlinje og andre ønskelige funksjonaliteter/features
- En skisse for løsningen har blitt utarbeidet, og blokkdiagram for den viktigste funksjonaliteten (Deployment f.eks.)
- En røff skjematikk er utarbeidet med de mest kritiske komponentene
- En røff beskrivelse av hva ”det fungerer” betyr er klargjort
- Alle komponentene som ikke er hyllevare er identifisert med pris, tilgjengelighet og datablader
- Det har blitt utviklet et røft budsjett for kostnader
- Det har blitt utviklet et røft budsjett for effekt (P) med estimater for maksimale effektforbruk, hvor høye spenninger og store strømmer som er nødvendige.
- En bring-up-plan har blitt dokumentert
- En endelig test-plan har blitt laget for å verifisere at ting fungerer
- En risikovurdering har blitt utviklet som lister opp de mest kritiske problemene, og indikasjon på løsninger
- Risikoreduserende tiltak har blitt planlagt, som kan innebære å lage en POC-versjon av systemet (proof of concept)
- Tiltak for å gjøre komponenter kompatible med breadboard har blitt iverksatt, dersom breadboard skal brukes
- En timeplan/tidsplan for når ting skal gjøres har blitt utviklet
- Dersom programvare skal utvikles, er det tilrettelagt en parallell plattform for programvareutvikling som kan benyttes til testing og utvikling
- Mot slutten av POR skal det gjennomføres en preliminary design review

Kortets/systemets funksjon:

En robotarm som navigerer til predefinerte posisjoner og fyller glass med væske automatisk når vektsensor registrerer at de er tomme. Systemet er ferdigstilt med Raspberry Pi, egenproduserte PCB-er, 3D-printede deler, PID-regulering og invers kinematikk.

Funksjonalitet (Grunnlinje):

1. Armen har servoer som kan bevege seg synkronisert
2. Pumpe som sender væske til tuppen av armen
3. En bordbrikke som har vekst sensor

Vellykket funksjonalitet

- Armen skal klare å bevege seg til en predefinert posisjon
- Armen beveger seg med jevn smoothstep-interpolasjon mellom posisjoner
- Pumpen gir en spesifikk mengde væske styrt av PID-regulator
- Systemet registrerer automatisk når et glass er under terskelverdi via tre HX711-lastceller og starter fylleprosessen

Ønsket ekstrafunksjonalitet:

- Armen har et kamera for å hjelpe å øke presisjon til glasset (ikke implementert – posisjonering løst med forhåndslagrede koordinater og invers kinematikk)

Foreslått løsning:

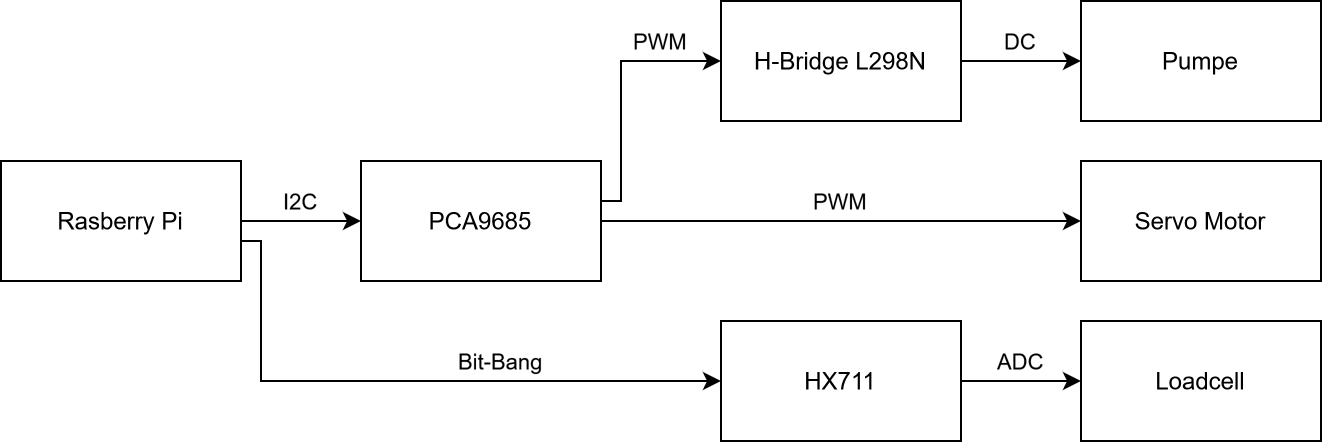
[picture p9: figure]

Skisse av løsning:

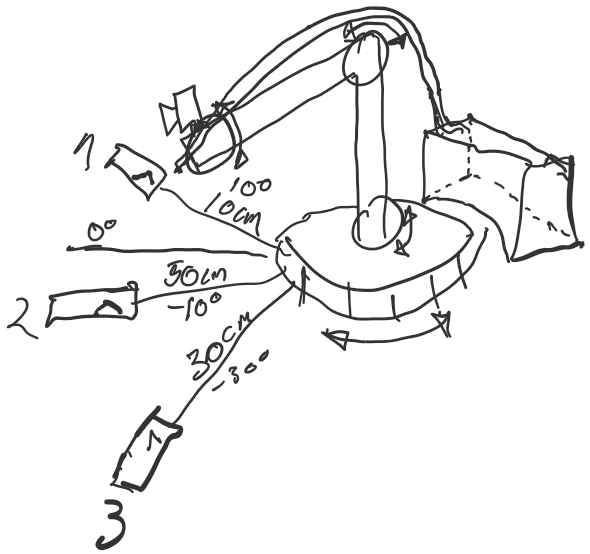
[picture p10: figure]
Håndskriftstegninger Håndskriftstegninger Håndskriftstegninger Håndskriftstegninger Håndskriftstegninger Håndskriftstegninger Håndskriftstegninger Håndskriftstegninger Håndskriftstegninger Håndskriftstegninger Håndskriftstegninger Håndskriftstegninger Håndskriftstegninger Håndskriftstegninger Hånd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

En røff skisse av helle prosjektet

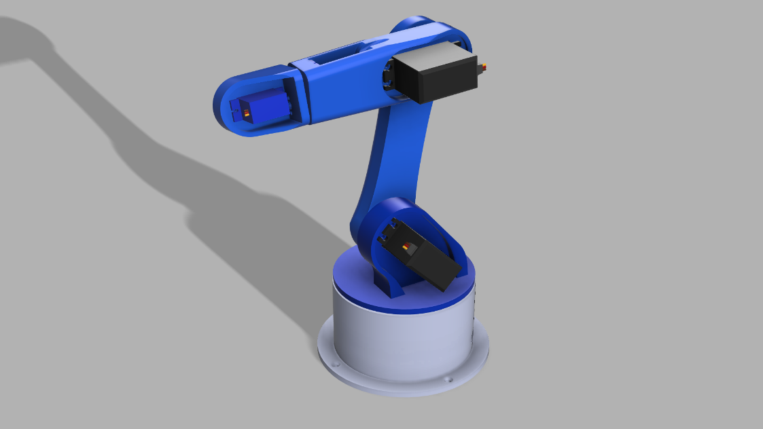
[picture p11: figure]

3D model armen som blir brukt i prosjektet hentet fra nett

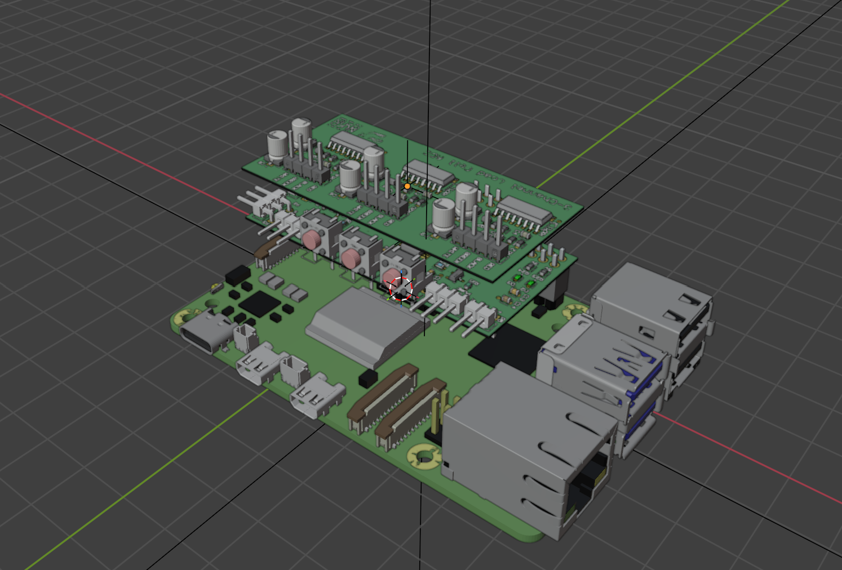
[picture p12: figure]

Skisse av overordnet skjematikk:

Liste over kritiske komponenter ():

Navn | Beskrivelse | Antall | Leveringstid
Power servo 6001 HB | | 3
DFROBOT DF9GMs servo | | 1
Loadcell 1kg | Måle vekt | 1 (3)
HX711 | 24-bit ADC for lastceller; bit-banging-protokoll via RPi GPIO. Tre chipper brukt, én per lastcelle. | 1
PCA9685 | I2C driver til PWM | 1
TC1508 | Ekstern H-bro-modul for pumpestyring med PWM (L298N kjøpt ferdig) | 1
Pumpe | | 1
Raspberry Pi 5 | Datamaskin | 1
PSU | En kombinert strømforsyning som gir ut 5V og 10V | 1

Omtrentlig budsjett:

Komponent | Antall | Stykkpris | Pris | Notat
Loadcell | 1 | 139 | 139 | Finner billigere vers
Servo | 3 | 1 | 697 | Veldig dyrt
Pumpe | 1 | 249 | 249 | Finn e-waste

Omtrentlig kraftbudsjett

Komponent | Antall | Effekt pr. komp. Max mA | Effekt pr. komp. Min mA | Effekt Max mA | Effekt Min mA
Pumpe | 1 | 350 | 0 | 350 | 0
Servo | 3 | 1500 | 300 | 4500 | 900
Micro servo | 1 | 1000 | 350 | 1000 | 350
RPI | 1 | 2150 | 500 | 2150 | 500
Tot | | | | 8000 | 1700

Risikofaktorer

1) Servo har ikke nok dreiemoment – skuldersevo med plastgir sviktet under høy belastning; løst ved bytte til metallgir-servo
2) Pumpe er ikke kraftig nok – ikke et problem i praksis; pumpen leverte tilstrekkelig mengde
3) Pris
4) Ikke nok amper – brownout inntraff på RPi ved høy belastning; løst ved kraftigere kabler direkte fra PSU til hoved-PCB

Risikoreduserende tiltak:

1) 3D printe robot armen for å minke vekt
2) Dobbel sjekk og teste forskjellige pumper (bare hvis vi finn e-avfall av pumper)
3) Prøv å finne e-avfall som kan bli brukt til prosjektet
4) En PSU med nok amper – PSU brukt, men tynne kabler forårsaket brownout; byttes til kraftigere kabler

Proof of Concept-versjon av systemet:

- Raspberry Pi kan kommunisere med PCA9685 over I²C
- PCA9685 kan styre minst én servo stabilt
- HX711 gir stabile og repeterbare vektverdier
- Pumpen kan startes og stoppes via RPI
- Pumpen gir repeterbar mengde ved fast kjøretid

Bring-up-plan:

Servo

- Koble til en servo
- Send PWM signal via PCA9685
- Verifiser at posisjon stemmer med kommando

Vektsensor

- Koble loadcell og HX711
- Bekreft at verdier endres ved trykk/last
- Kalibrere og Tare måledata

Pumpe

- Kjør pumpen i korte pulser
- Kjør pumpen i 10 sekunder
- Mål og sammenlign levert mengde

Integrasjon

Les vekt, aktiver pumpe, stopp, les vekt på nytt

Fullstendig testplan:

- Koble servo motorene til PCA9685 og se hvis den kommunisere med RPI
- Koble opp L298N H-bro og verifiser at pumpe kan startes, stoppes og reverseres via PWM og GPIO
- Teste pumpen med H-bridge og se den kan pumpe væske
- Feste servoene til 3D prentet komponentene og deretter teste bevegelse
- Prøv å fylle glass

Tidsplan:

Skjematikk og BOM | Uke 6
Utlegg | | Uke 7 | Uke 9
3D- printing av deler | | Uke 6-7 | Uke 9
Laser kutting av deler
Lodding av kort | | | | Uke 10
Utvikling av enkel POC | | Uke 7
SW-utvikling med POC | | | Uke 9 | Uke 10
Montering og testing | | | | Uke 10 | Uke 15
SW-utvikling med V1 | | | | | Uke 15
Testing av V1 | | | | | Uke 15
Dokumentasjon | | | | | Uke 19-22

Use-Case-diagram:

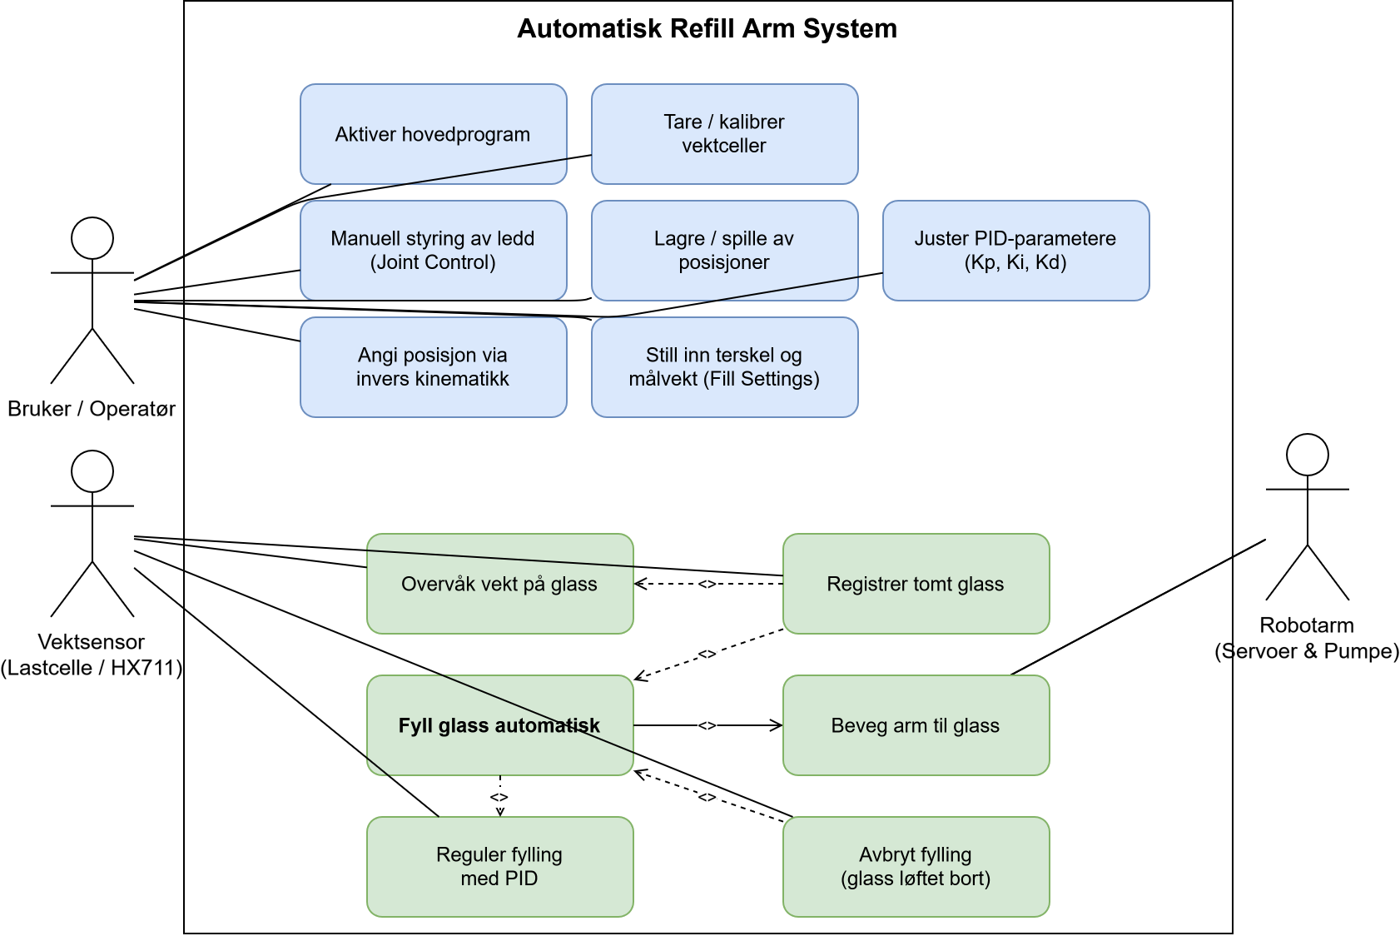
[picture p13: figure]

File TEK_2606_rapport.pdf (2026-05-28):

## Automatisk refill arm

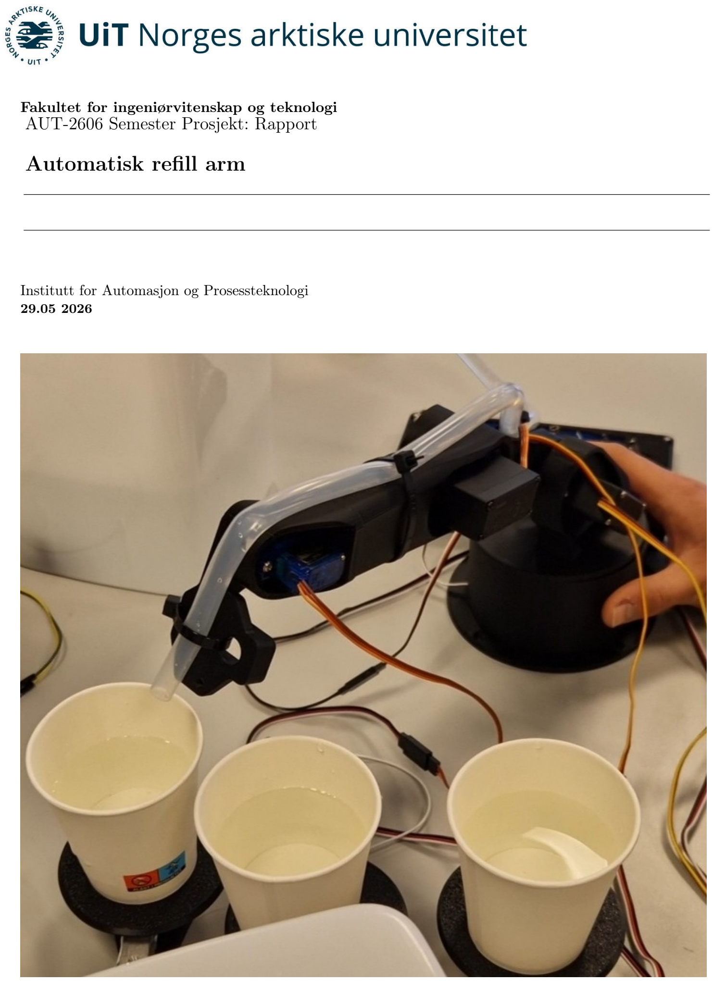
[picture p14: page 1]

Fakultet for ingeniørvitenskap og teknologi AUT-2606 Semester Prosjekt: Rapport

Institutt for Automasjon og Prosessteknologi 29.05 2026

Innhold

1 Sammendrag | 1
2 Introduksjon | 1
3 Teori | 1
3.1 Raspberry Pi | | 1
3.2 PCA9685 | | 1
3.2.1 | I2C | | 1
3.3 HX711 | | 2
3.3.1 | Bit bang | | 2
3.4 Dual H-Brigde L298N module | | 2
3.5 Regulering | | 2
3.6 Invers kinematikk | | 3
4 Metode | 4
4.1 Testing før mottatt PCB | | 4
4.2 Kretsen | | 4
4.3 Beste praksis for PCB-design | | 6
4.4 Programmering | | 6
4.4.1 | PCA9685 | | 6
4.4.2 | HX711 | | 6
4.5 main.py | | 7
4.5.1 | Importerte biblioteker | | 8
4.5.2 | Servostyring | | 8
4.5.3 | Tilstand | | 8
4.5.4 | Invers kinematikk | | 9
4.5.5 | Jevn bevegelse | | 9
4.5.6 | PID-regulator | | 9
4.5.7 | Fylleprosess | 10
4.5.8 | Hovedløkke | 10
4.5.9 | GUI | 11
4.5.10 Avslutning | 12
5 Resultat | 12
5.1 PCB | 12
5.2 Arm | 13
6 Diskusjon | 14
7 Konklusjon | 15
8 Kildehenvisning | 16
9 Vedlegg | 17

Figurer

1 | PID sløyfe | | 2
2 | Diagram over robotarmens geometri med tre frihetsgrader | | 3
3 | 3D model av robot arm | | 4
4 | Transistor oppsett | | 6

i

5 | Package Diagram | | 7
6 | Tilstandsdiagram | | 9
7 | GUI | 12
8 | Hoved PCB og HX711 PCB | 13
9 | Endringene som ble gjort på PCB-en | 13
10 | Se vedlegg mappe for videoen | 17
11 | Deployment Diagram | 17
12 | Use-Case Diagram | 17
13 | Hoved kretskjema der alle individe komponenter ble satt sammen | 18
14 | Pi interface som inkludere PCA9685, PWM switchers, og knapper | 19
15 | Hoved PCB | 19
16 | Individ Hx711 krets | 20
17 | HX711 PCB | 20

Tabeller

1 | Komponentliste (BOM) for PCB-ene | | 5

Kodeutdragsliste
1 | HX711 avlesing Kodeutdrag | | 7
2 | Servo styring Kodeutdrag | | 8
3 | Bevegelse Kodeutdrag | | 9
4 | PID regulering Kodeutdrag | 10
5 | Hovedløkke Kodeutdrag | 11
6 | Avsluttning Kodeutdrag | 12

### 1. Sammendrag

Vi har satt oss fore å lage en maskin som viser vår kunnskap om mekanismer, PCB-design og programmering. Hovedsystemet er satt sammen av en Raspberry Pi, tilpassede PCB-er, 3D-printede deler og andre elektronikkomponenter. Vi har tilpasset alle komponenter slik at de passer sammen, og designet PCB-ene for å levere den nødvendige funksjonaliteten: PWM-utganger, I/O-knapper, HX711 loadcell-brikker og dedikerte I2C-tilkoblinger. Programvaren gir PID-regulering, IK-posisjonering og tilstandsmaskiner. Til slutt har vi bygget, testet, feilrettet og ferdigstilt en robotarm som fyller glass når vektsensoren registrerer at de er tomme. Vi har dermed nådd målet for semesterprosjektet.

### 2. Introduksjon

I dette semesterprosjektet har vi laget en automatisk refill-arm, en robotarm som fyller glass med væske når en vektsensor registrerer at de er tomme. Prosjektet er gjennomført i emnet AUT-2606 ved Institutt for Automasjon og Prosessteknologi, og målet har vært å vise og videreutvikle vår kunnskap innen mekanismer, PCB-design og programmering.

Rapporten gir først en gjennomgang av det teoretiske grunnlaget for komponentene og metodene som er brukt, blant annet regulering og invers kinematikk. Deretter beskrives metodikken bak design av kretsen, lodding og programvaren, før vi presenterer og diskuterer resultatene fra det ferdige systemet.

### 3. Teori

3.1. Raspberry Pi
Raspberry Pi er datamaskinen i dette prosjektet. Det ble valgt for å bruke RPi fordi det er en kraftig datamaskin som kan kjøre programmer raskt, samtidig som den har GPIO-pinner som gir mulighet for tilkobling av ekstern tilkobling. RPi-en kan også kobles til GitHub, noe som gir en raskere og enklere arbeidsflyt. I tillegg støtter RPi-en alle kommunikasjonsprotokollene vi trengte i prosjektet, blant annet I2C og bit bang.
3.2. PCA9685
For å kunne kontrollere flere servomotorer samtidig ved bruk av RPi-en, brukte man chippen PCA9685. Denne gjør det mulig å styre opptil 16 servomotorer via I2C, med presise og stabile PWM signaler enn hva RPi-en kan gi.
3.2.1. I2C
I2C er kommunikasjon protokollen som blir brukt i PCA9685. I2C blir vanligvis brukt å koble mellom mikrokontrollere og sensorer, minnebrikker og andre enheter.

Buss strukturen til I2C er en synkron toveis kommunikasjonsbuss som kun benytter av to ledere: SDA (Serial Data) som er linjen som overfører data og SCL (Serial Clock) som er klokken som synkroniserer dataoverføringen laget av master enheten.

Kommunikasjonen bruker master og slave prinspit. Det er en master enhet (vanligvis en mikrokontoler eller RPi i dette prosjektet) som styrer klokkesignalet og initialerer komunaksjonen. Og slave enheter svarer når kun de er addresert. Man kan tenke seg slikk at master enheten er posten som levere ut inviasjonen og slaven kan bare svare hvis de har fått invitasjoner. Hver slave har en unik addresse som er regel på 7 bit. Det gir i teori opp til 128 enheter på samme buss linje.

Data overføring skjer ved at, masteren sender en startbetingelse (SDA går lav mens SCL er høy). Masteren sender slavens 7-bits adresse. Den adresserte slaven svarer med et ACK-bit (acknowledge) for å bekrefte at den er tilstede. Data overføres byte for byte. Hvor hver byte følges av et ACK eller NACK bit fra mottakeren. Masteren avslutter med en stoppbetingelse (SDA går høy mens SCL er høy).

1

3.3. HX711
For å måle vekten på glassene brukte vi chippen HX711. Denne chippen leser av analoge signaler fra en lastcelle og konverterer dem til digitale data. HX711 er en 24 bits analog til digital omformer (ADC) spesielt beregnet for lastceller. Chippen kommuniserer med RPi-en via sin egen serielle protokoll basert på bit-banging. Siden hver HX711 kun kan lese fra en lastcelle, måtte vi ta i bruk tre chipper for å kunne lese av tre lastceller.
3.3.1. Bit bang
Bit banging er en teknikk der en kommunikasjonsmetode implementeres direkte i programvaren i stedet for ved hjelp av dedikert maskinvare. I stedet for å bruke allerede eksisterende bibliotek eller maskinvaremoduler i mikrokontrolleren, tolkes signalene ved at programvaren selv styrer en signallinje høy eller lav i riktig rekkefølge og med riktig timing.

Ved bit banging er det programvaren som tar seg av alle detaljene i protokollen. Dette går på å sette tilstanden på hver GPIO-pinne som er i bruk, manuelt. Å generere klokkesignalet ved å veksle mellom høyt og lavt. Å beholde timingen og håndtere rekkefølgen på bitene.

3.4. Dual H-Brigde L298N module
Modulen bruker både 5V og 12V. Den mottar et PWM-signal og har i tillegg en «HIGH-pin» og en «LOWpin» som bestemmer hvilken retning pumpen går. Bytter man om på disse to pinnene, snur pumpe retningen.

Modulen er en dobbel bidireksjonell H-bro. Det betyr at den kan styre to DC-motorer samtidig uavhengig av hverandre. En H-bro er en standard-krets av fire transistorer satt sammen i en form som ligner på bokstaven H, hvor motoren er plassert i midten. Med å aktivere diagonalt motsatte transistorer kan strømmen gå gjennom motoren, og å aktivere motsatte transistorer vil de gå motsatt vei.

PWM-signalet brukes til å styre hastigheten på motoren. PWM-en veksler raskt mellom «HIGH» og «LOW», og forholdet mellom "HIGHtid og LOWtid kalles «duty cycle». En høy duty cycle gir motoren høyere hastighet, mens en lav duty cycle gir lavere hastighet.

3.5. Regulering
For å fylle glasset og sikre at det blir fylt opp uten søl, brukes en form for regulering. En regulator sin oppgave er å styre et system slik at den målte y(t) følger en ønsket referanseverdi så presist som mulig. I dette prosjektet styres pumpen ut fra hvor mye væske som skal være i glasset, slik at fyllingen stoppes på

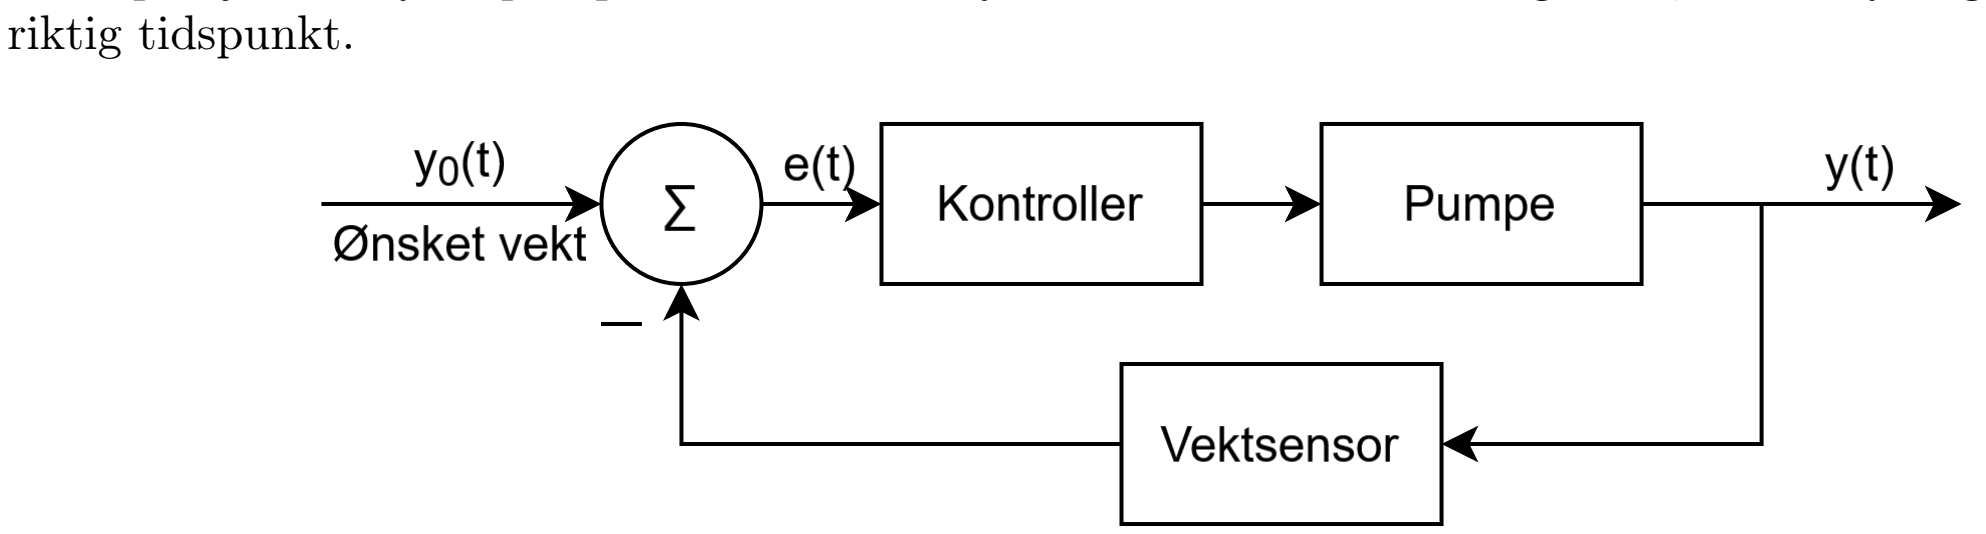
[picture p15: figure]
riktig tidspunkt.

Figur 1: PID sløyfe

Reguleringen er bygget opp som en lukket sløyfe. Det innebærer at den målte y(t) kontinuerlig sammenlignes med referanseverdien, og at differansen mellom dem brukes til å bestemme pådraget. Feilsignalet er definert som differansen mellom referanseverdien y0(t) og målte ut verdien y(t):

e(t) = y0(t) − y(t) | (1)

2

Uten PID følger kontrolleren en på/av-logikk:

u(t) = (
1 hvis e(t) > 0
0 hvis e(t) ≤ 0

(2)

For å oppnå en jevnere og mer presis styring brukes en PID regulator. PID regulatoren består av: et proporsjonalt ledd (P), et integrasjoins ledd (I) og et deriverende ledd (D).

Og under er Kp, Ki og Kd forsterkningskonstantene for henholdsvis proporsjonal, integral og derivasjons leddet. Disse må tunes inn for å gi ønsket oppførsel, der målet er en rask respons med lite oversving og liten stasjonær feil og unngå oscillasjon.

u(t) = Kp · e(t) + Ki

Z t

0

e(τ ) dτ + Kd

de(t)
dt | (3)

Den diskrete formelen som brukes i koden er:

u[k] = Kp · e[k] + Ki

X

k

j=0

e[j] · ∆t + Kd

e[k] − e[k − 1]
∆t

(4)

Integralleddet er her tilnærmet med en Riemann sum, der feilen i hvert tidssteg multipliseres med ∆t og summeres opp. Derivasjonsleddet er tilnærmet med baklengs differanse (finite difference), altså endringen i feilsignalet fra forrige til nåværende tidssteg delt på ∆t. Disse tilnærmingene blir mer nøyaktige jo mindre ∆t er.

3.6. Invers kinematikk
For å styre bevegelsen til robotarmen brukte vi en forenklet versjon av invers kinematikk. Vi valgte invers kinematikk fremfor fremoverkinematikk fordi fremoverkinematikk beregner endepunktet ut fra kjente leddvinkler, mens invers kinematikk gjør det motsatte den beregner nødvendige leddvinkler for å oppnå en ønsket endeposisjon. Robotarmens geometri er illustrert i figur 2.


Figur 2: Diagram over robotarmens geometri med tre frihetsgrader.

3

Definerer håndleddspunktet (xw, yw) ved å trekke fra bidraget fra det siste leddet med lengde L3:

xw = x − L3 cos(φ) | (5)
yw = y − L3 sin(φ) | (6)

Vinkelen θ2 finnes ved hjelp av cosinussetningen:

cos(θ2) = x

2
w + y

2
w − L

2
1 − L

2
2
2L1L2

(7)

θ2 = atan2
±

p
1 − cos²(θ2), cos(θ2)
(8)

Deretter beregnes θ1 og θ3:

θ1 = atan2(yw, xw) − atan2(L2 sin(θ2), L1 + L2 cos(θ2)) | (9)
θ3 = φ − θ1 − θ2 | (10)

### 4. Metode


Figur 3: 3D model av robot arm

4.1. Testing før mottatt PCB
Siden produksjon og levering av PCB-ene tok tid, var det viktig å verifisere at de sentrale komponentene og kommunikasjonsprotokollene fungerte før kortene kom i posten. Raspberry Pi-en ble stilt til rådighet av universitetet tidlig i prosjektet, og vi brukte derfor denne til å teste de ulike delene av systemet hver for seg på forhånd.

Først testet vi I2C-kommunikasjonen, ettersom denne er avgjørende for styringen av servomotorene. Ved hjelp av en frittstående PCA9685-modul koblet til Raspberry Pi-en kunne vi bekrefte at Pi-en oppdaget enheten på I2C-bussen, og at vi klarte å generere stabile PWM-signaler ut fra modulen. På denne måten fikk vi verifisert både selve I2C-oppsettet og at vi kunne styre en servomotor via PCA9685 før dette ble integrert på vårt eget kort.

4.2. Kretsen
Vi tok hva vi hadde i POR-en for å finne ut hvilke funksjoner som var nødvendige, og hvilke som kunne inkluderes om vi hadde plass til det. Vi fant ut at kortet skal gi ut fem PWM-signaler, tre knapper, muligheten strømtilførsel uten USB-C, fire ledige pins for I2C-kommunikasjon, samt tre HX711-brikker for loadcells.

4

Tabell 1: Komponentliste (BOM) for PCB-ene.

Description | Designator | Mfr. Part Number | Supplier | Qty
CAP ALUM 10UF 20% 35V SMD | C1, C2, C5, C6,
| C7, C8 | EDK106M035A9BAA | Farnell | 6
CAP CER 0.1UF 25V X7R 0603 | C3, C4, C9, C10,
| C11, C12 | C0603C104K3RAC7411 | Mouser | 6
CAP CER 10UF 10V X5R 0603 | C13 | GRM188R61A106KE69D | Arrow | 1
CC0603 100 nF X7R 10% 25 V | C14, C15, C16, C17 | CC0603KPX7R8BB104 | Mouser | 4
LED GREEN CLEAR CHIP SMD | D2, D3 | LTST-C193KGKT-5A | DigiKey | 2
Female header, 40C, straight, 2.54 mm, PBT/phos bronze | J2 | PPPC202LFBN-RC | DigiKey | 1
CONN HEADER VERT 4POS 2.54MM | J3, J4, J5 | TSW-104-23-T-S | Arrow | 3
CONN HEADER VERT 6POS 2.54MM | J6 | M20-9980346 | DigiKey | 1
SQ post socket, TH, vertical, 2.54 mm, 6-pin, female | J7 | SSW-103-01-L-D | DigiKey | 1
0.025SQ post header, TH, right-angle, 2.54 mm, 2-pin, male | P5 | TSW-102-22-G-S-RA | Arrow | 1
TRANS NPN 40V 0.2A SMD SOT23-3 | Q1, Q2, Q3, Q8, Q9 | MMBT3904-7-F | Farnell | 5
Transistor PNP, 3-pin SC-75, Pb-free | Q5, Q6, Q7 | MMBT3906TT1G | Mouser | 3

RES thick film, 20 kΩ, 1%, 0.33W,
0603 | R1, R10, R13, R14,
| R17, R18 | CRCW060320K0FKEAHP | Arrow | 6
RES thick film, 10 kΩ, 1%, 0.2W, 0603, AEC-Q200 | R2, R4, R6, R7,
| R21 | SG73P1JTTD1002F | Mouser | 5
RES thick film, 1 kΩ, 1%, 0.1W, 0603, AEC-Q200 | R3, R5, R8, R9,
| R22 | RK73G1JTTD1001F | Farnell | 5
RES SMD 100 Ω 1% 1/10W 0603 | R11, R12, R15,
| R16, R19, R20 | RT0603FRE07100RL | Arrow | 6

RES thick film, 2.2 kΩ, 5%, 0.1W,
0603 | R23 | RC1608J222CS | Arrow | 1
RES thick film, 3.3 kΩ, 5%, 0603 | R24 | CRGCQ0603J3K3 | Arrow | 1
SWITCH TACTILE SPST-NO 0.05A 24V | SW1, SW2, SW3 | B3F-3122 | Arrow | 3

Ved bruk av Raspberry Pi-en ble hovedprosesseringen og styringen forenklet. Pi-en ga en fornuftig måte å kommunisere med de andre komponentene på, via I2C, bit-banging og innlesing gjennom GPIO-pinnene.

Først fant vi ut hvordan PWM-utgangene skulle styres. PWM-signalet genereres ikke direkte av Raspberry Pi-en, men av en PCA9685 PWM-driver som Pi-en kommuniserer med over I2C. Figur 4 viser hvordan transistoren brukes. Signalet fra PCA chippen føres til PWM inngangen i kretsen, der strømmen går gjennom en motstand som begrenser basestrømmen til transistoren. Transistoren er en NPN BJT som opererer i en «common-emitter»-konfigurasjon, det vil si at emitteren er felles for inngangen og utgangen. Deretter er collector-pinnen koblet til en pull-up-motstand.

Når PWM-signalet er høyt, driver basestrømmen transistoren til saturation. Collectoren blir da trukket ned mot GND, og utgangen settes lav. Når PWM-signalet er lavt, går det ingen strøm til basen, og transistoren er «av». Da går det ingen strøm gjennom pull-up-motstanden, og utgangen trekkes høy til 5V.

5

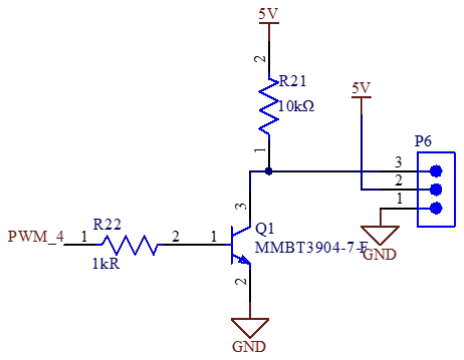
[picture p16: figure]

Figur 4: Transistor oppsett

Hx711 kretsen var en ukjent komponent som krevet mye forskning. Hoved krets design/oppsett kom fra en produsent som leverer ferdig bygget Hx711 PCB-er.

4.3. Beste praksis for PCB-design
Avkoblingskondensatorer: Hver aktive komponent ble utstyrt med avkoblingskondensatorer plassert så nær forsyningspinnene som mulig. PCA9685 og HX711-brikkene har dedikerte 100nF keramiske kondensatorer for å filtrere ut høyfrekvent støy, samt større 10 µF elektrolytt-/keramiske kondensatorer for å stabilisere forsyningsspenningen ved raske lastendringer.

Jordplan: Kortet ble lagt ut med et sammenhengende jordplan (kobberfyll for GND). Et jordplan gir lav impedans tilbake til forsyningen og korte returbaner for signalstrømmene, noe som reduserer støy og gir mer stabile referansenivåer. Dette er særlig fordelaktig for de analoge målesignalene fra lastcellene, der et stabilt jordreferansenivå er avgjørende for nøyaktige avlesninger.

Sporbredde for forsyning: Spor som fører forsyningsstrøm (5V og 12V) ble tegnet merkbart bredere enn signalspor. Bredere spor har lavere resistans, noe som reduserer spenningsfallet og varmeutviklingen ved høyt strømtrekk. Dette er viktig i et system der servoer og pumpe kan trekke betydelig strøm samtidig.

Separasjon av analoge signaler: De analoge linjene fra lastcellene ble bevisst holdt adskilt fra PWM- og effektspor. Ved å unngå at følsomme målesignaler rutes parallelt med eller krysser støyende spor, reduseres innkobling av støy på HX711-avlesningene.

4.4. Programmering
4.4.1. PCA9685
PCA9685 chippen kommuniserer gjennom I2C og siden PCA9685 er en ganske populær chip som blir brukt mye gjennom hobby for å klare å styre flere servomotorer samtidig, så er det allerde en eksisterte bibliotek på python for denne chippen.
4.4.2. HX711
HX711 bruker sin egen type protokoll for kommunikasjon. Hvor RPi-en sender en 24 klokke pulser og for hver puls sender chippen ut et bit. Fra dette kan vi få data ut fra loadcellene som kan tolkes til vekt.

6

HX711-kretsen kommuniserer ikke over en standardisert maskinvarebuss, men bruker en egen toleders protokoll bestående av en datalinje (DT) og en klokkelinje (SCK). Denne protokollen er implementert i programvare ved bit banging. Innlesningen foregår slik: programmet venter først til datalinjen går lav, noe som signaliserer at kretsen har en ny måling. Deretter genereres klokkesignalet manuelt ved at SCK veksles høy og lav 24 ganger i en løkke. For hver klokkepuls leses en bit fra datalinjen og skiftes inn i et register. Til slutt sendes noen ekstra klokkepulser som velger kanal og forsterkning på kretsen, og hele resultatet på 24 bit settes sammen til ett tall som tolkes som et signert toerkomplement. Hele innlesningen er vist under:

1 | def read_raw ( self ) -> int:
2 | timeout = time . time () + 1.0
3 | while self . dt . value == 1:
4 | if time . time () > timeout :
5 | raise TimeoutError (" HX711 not responding , check wiring ")
6 | raw = 0
7 | # Lock the shared clock so concurrent sensors dont corrupt each others reads
8 | with sck_lock :
9 | for _ in range (24) :
10 | sck . on ()
11 | raw = ( raw << 1) | self . dt . value
12 | sck . off ()
13 | for _ in range ( GAIN_PULSES - 24) :
14 | sck . on ()
15 | sck . off ()
16 | if raw & 0 x800000 :
17 | raw -= 0 x1000000
18 | return raw

Kodeutdrag 1: HX711 avlesing Kodeutdrag

Til slutt sendes noen ekstra klokkepulser som velger kanal og forsterkning på kretsen. Hele resultatet på 24 bit settes så sammen til ett tall som tolkes som et signert toerkomplement. Siden flere sensorer i prosjektet deler den samme klokkelinjen, beskyttes klokkegenereringen av en lås sck\_lock slik at to sensorer ikke kan flette seg inn i klokkepulser i hverandres innlesning samtidig.

4.5. main.py
Programmet styrerer helle systemet samt og knytter sammen brukergrensesnittet (GUI), sensoravlesningen, servostyringen og pumpe reguleringen. Dette består av seks hoveddeler: import av nødvendige biblioteker, servostyring, invers kinematikk og PID-regulering, en tilstandsmaskin for fylle prosessenn og en hovedløkke som henter information fra vektcellene.

Figur 5: Package Diagram

7

4.5.1. Importerte biblioteker
- tkinter - brukes til å lage brukergrensesnittet (GUI)
- time - brukes til tidsmåling i PID regulatoren
- math - brukes til trigonometriske beregninger i invers kinematikk
- adafruit_servokit - brukes til å styre servomotorene via PCA9685-driveren over I2C
- hx711 - egen modul for avlesning av vektceller
- gpiozero - brukes til å styre GPIO-pinner, som pumpen og de fysiske tare knappene
4.5.2. Servostyring
Funksjonen drive() er den for å styre servoene på. Den tar inn fire leddvinkler (midje, skulder, albue, wrist) i grader samt en pumpe i prosent og oversetter disse til en duty cycle"mellom 2350 og 5650. Disse to verdiene ble funnet etter noen forsøk der tallene ble justert mens PWM-signalet ble observert på oscilloskop. Dette området tilsvarer omtrent 800µs til 2200µs i pulsbredde. Verdiene sendes til PCA9685-driveren via ServoKit. Alle andre funksjoner i programmet som beveger armen bruker drive().
1 | def drive ( midje , skulder , albue , wrist , pump ) :
2 | min = 2350
3 | max = 5650

4
5 | def angle_to_us ( deg ) :
6 | return int(max - (( max - min ) * ( deg / 90) ) )

7
8 | kit . _pca . channels [0]. duty_cycle = 65535 - angle_to_us ( midje )
9 | kit . _pca . channels [1]. duty_cycle = 65535 - angle_to_us ( skulder )
10 | kit . _pca . channels [2]. duty_cycle = 65535 - angle_to_us ( albue )
11 | kit . _pca . channels [3]. duty_cycle = 65535 - angle_to_us ( wrist )

12
13 | desired_duty = int( pump / 100 * 65535)
14 | kit . _pca . channels [4]. duty_cycle = 65535 - desired_duty

Kodeutdrag 2: Servo styring Kodeutdrag

4.5.3. Tilstand
Programmet bruker en global tilstandsmaskin med tre tilstander for fylleprosessen:
- idle - systemet venter og overvåker vektcellene
- moving - armen beveger seg mot riktig glass
- filling - pumpen er aktiv og PID-regulatoren styrer fyllingen

8

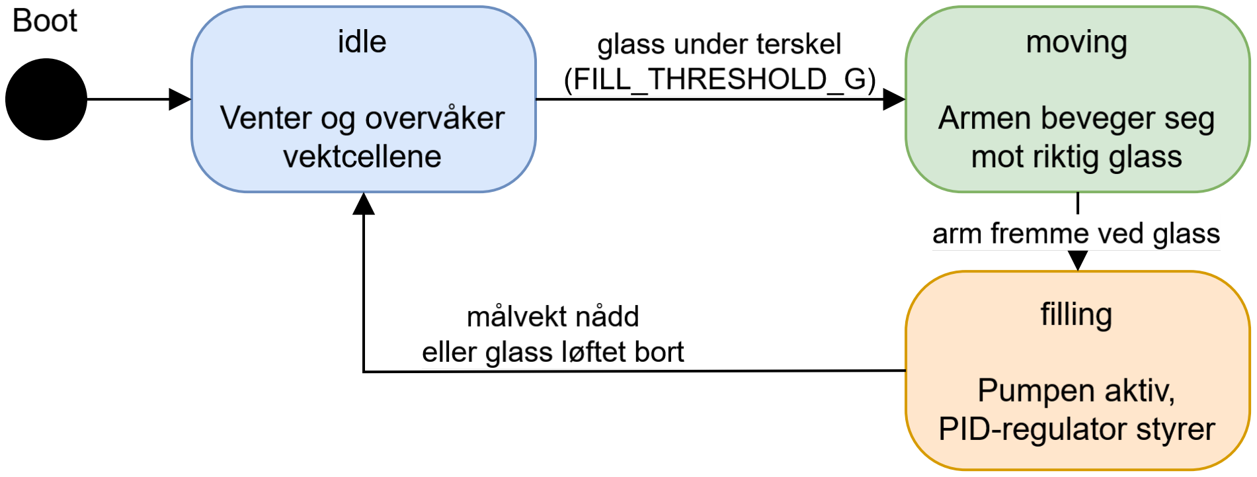
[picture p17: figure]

Figur 6: Tilstandsdiagram

4.5.4. Invers kinematikk
Funksjonen solve_ik() beregner leddvinklene som trengs for å sette armens tupp i ønsket posisjon (x, y, z) med ønsket orientasjon ϕ. Beregningen er basert på armens lengder L1, L2 og L3, samt basehøyden Zbase fordi den ligger litt over nullpunktet (0, 0, 0). Skuldervinkelen finnes ved trigonometri ut fra håndleddspunktet, mens albuvinkelen beregnes med cosinussetningen. Til slutt justeres vinklene for hvordan servoene er montert, slik at de kan sendes rett til servoene.

I den nåværende implementasjonen brukes solve_ik() kun når brukeren skriver inn koordinater i IK-feltet i GUI-et. Når armen kjører automatisk beveger armen seg i stedet til posisjoner som er lagret manuelt på forhånd.

4.5.5. Jevn bevegelse
Funksjonen smooth_step() beregner ut små delsteg mellom nåværende posisjon og målposisjonen over et fast antall steg (MOVE_STEPS, standard 40) med MOVE_MS millisekunder mellom hvert steg. Dette følger en smoothstep-kurve, t

2
(3 − 2t), slik at bevegelsen starter sakte, akselererer i midten og bremser mot slutten. Dette gir jevnere og mer kontrollert bevegelse enn en lineær interpolasjon.
1 | def smooth_step ( step ):
2 | t = step / MOVE_STEPS
3 | t = t * t * (3 - 2 * t )
4 | interp = [ _move_start [ i ] + ( _move_target [ i ] - move_start [ i ]) * t for i in
| range (5) ]
5 | set_joints ( interp )
6 | if step < MOVE_STEPS :
7 | root . after ( MOVE_MS , lambda : smooth_step ( step + 1) )

Kodeutdrag 3: Bevegelse Kodeutdrag

4.5.6. PID-regulator
Funksjonen pid_control() bruker er en diskret PID-regulator. Regulatoren styrer pumpeeffekten basert på forskjellen mellom ønsket vekt og målte vekt fra vektcellen. Standardverdiene til PID regulatoren er satt til:
- Kp = 0,15
- Ki = 0,01
- Kd = 0,00

9

Disse kan justeres direkte i GUI-en.

1 | def apply_pid () :
2 | global kp , ki , kd , integral , prev_error , prev_time
3 | kp = pid_kp_var . get ()
4 | ki = pid_ki_var . get ()
5 | kd = pid_kd_var . get ()
6 | integral | = 0
7 | prev_error = 0
8 | prev_time | = time . time ()
9 | pid_status . config ( text = f" Active : Kp ={ kp} | Ki ={ ki} | Kd ={ kd}", fg =" green ")

Kodeutdrag 4: PID regulering Kodeutdrag

4.5.7. Fylleprosess
Fylleprosessen styres av fire funksjoner:
- start_fill() - setter tilstanden til moving og flytter armen til riktig glass via go_to()
- begin_pump() - aktiverer pumpen, nullstiller PID-tilstanden og setter tilstanden til filling
- pid_fill_loop() - kjører PID-regulatoren i en løkke med PID_POLL_MS intervall (standard 500 ms) til målvekten er nådd
- stop_pump() - slår av pumpen og returnerer tilstanden til idle

Hvis vektcellen leser er negativ verdi før eller under fylling tolkes dette som at glasset er løftet bort og avbrytes automatisk fyllingen.

4.5.8. Hovedløkke
Funksjonen main_loop() kjøres hvert 500ms og leser av alle tre vektcellene. Hvis systemet er aktivert via Activate Main Program-knappen og et glass er under terskelverdien FILL_THRESHOLD_G (standard 150g) vil fylleprosessen starte automatisk for det aktuelle glasset. Negative avlesninger ignoreres, slik at et glass som er løftet av vekten ikke starter fyllingen fylling.

10

1 | def main_loop () :
2 | if not activate or fill_state != " idle ":
3 | root . after (500 , main_loop )
4 | return
5 | sensors = [ hx711 . sensor1 , hx711 . sensor2 , hx711 . sensor3 ]
6 | for idx , sensor in enumerate ( sensors ) :
7 | try :
8 | grams = sensor . read_grams ()
9 | if grams < 0:
10 | continue | #lø ftet glass
11 | if grams < FILL_THRESHOLD_G :
12 | start_fill ( idx ) # fyll glass
13 | return
14 | except Exception :
15 | pass
16 | root . after (500 , main_loop )

Kodeutdrag 5: Hovedløkke Kodeutdrag

4.5.9. GUI
GUI-et er bygget med tkinter og inneholder:
- Joint Control - glidere for manuell styring av hvert ledd (midje, skulder, albue, wrist) samt pumpe
- Inverse Kinematics - inntastingsfelt for målposisjon (x, y, z, ϕ) og geometriparametere
- Saved Positions - lagring og avspilling av inntil tre posisjoner med jevn interpolasjon
- Load Cell - sanntidsavlesning av alle tre vektceller med valg mellom live og en median modus
- Tare og Kalibrering - nullstilling og kalibrering av vektcellene, både via GUI og via fysiske knapper koblet til GPIO
- Fill Settings - innstilling av terskel og målevekt for fylling
- Water Level - fremdriftsindikatorer som viser fyllingsnivå for hvert glass
- PID Controller - felt for Kp, Ki og Kd med knapp for å anvende nye verdier under kjøring

11

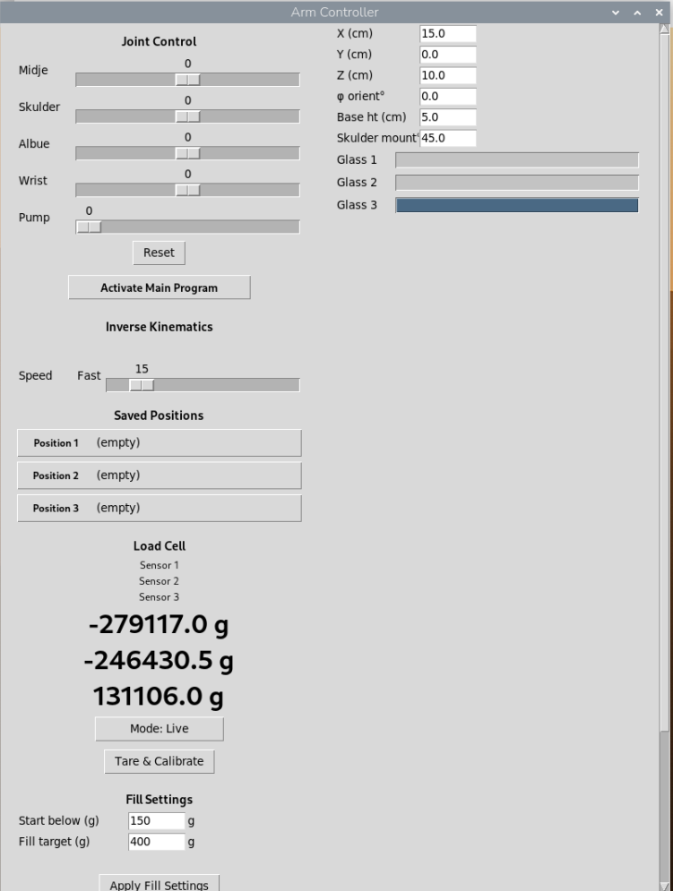
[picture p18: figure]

Figur 7: GUI

4.5.10. Avslutning
Når programmet avsluttes frigjøres det alle ressurser:
1 | hx711 . sensor1 . close ()
2 | hx711 . sensor2 . close ()
3 | hx711 . sensor3 . close ()
4 | hx711 . sck . close ()
5 | pump_fwd . close ()

Kodeutdrag 6: Avsluttning Kodeutdrag

### 5. Resultat

5.1. PCB
Ved testing av PCB-en viste tre punkter som måtte justeres før kortet nådd full funksjonaletet. PCB-en fungerte ellers som planlagt, og justeringer kunne utføres direkte på kortet uten å bestille på nytt.

12

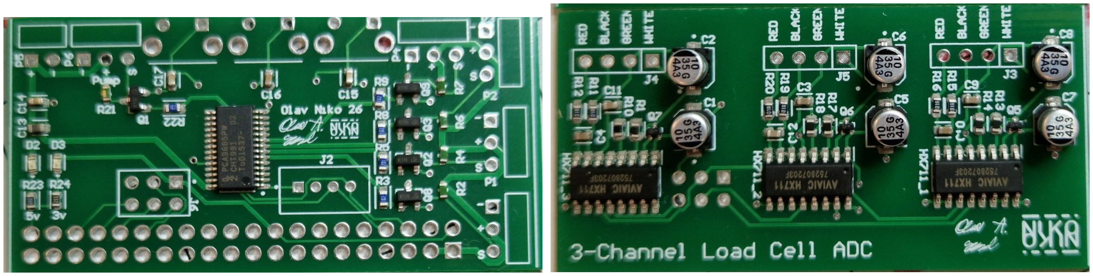
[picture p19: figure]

Figur 8: Hoved PCB og HX711 PCB

Det første punktet var at OE-pinnen på PCA9685 ble latt flytende. Pinnen aktiveres når den er lav, ikke var koblet til jord. Dette løste vi ved å lodde en bru mellom den pinnen og en nærliggende pinne som var koblet til jord.

Det andre punktet var at den SDA ledningen på PCB-en var ikke koblet til SDA pinnen på PI-en. Dette kunne i prinsippet løses ved å konfigurere den ikke-dedikerte pinnen for I2C gjennom programvaren på RPi-en, men siden denne pinnen manglet pull-resistor, valgte vi i stedet å bygge om forbindelsen med en kabel.

Det tredje punktet var at styringen av pumpe motoren krevde en pinne som kunne settes både lav og høy for å aktivere og deaktivere H-broen. Dette ble løst ved å lodde på en ekstra pinne.

Etter at disse justeringene ble gjort, verifiserte vi kortet ved hjelp av enkle testprogrammer som kjører en funksjon om gangen. Deretter kunne vi bekrefte at alle delkomponenter av PCB-en fungerte som de skal.

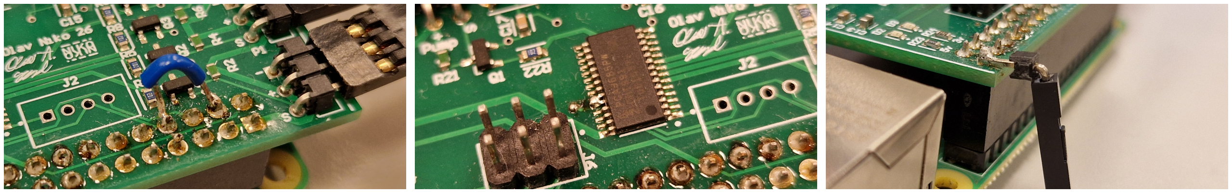
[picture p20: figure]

Figur 9: Endringene som ble gjort på PCB-en

5.2. Arm
Testingen ble gjennomført trinnvis, der de ulike delene av systemet først ble verifisert hver for seg. De tre forhåndsbestemte posisjonene ble testet for å bekrefte at armen klarte å bevege seg mellom de lagrede posisjonene. Deretter ble det verifisert at pumpen startet når loadcellen registrerte at vekten kom under terskelverdien, og stoppet når vekten kom over ønsket mengde, samt at pumpen ikke startet dersom koppen ble tatt av brikken. Til slutt ble systemet testet med vann. Da delfunksjonene ble kombinert, fungerte de sammen som en tilstandsmaskin: tilstandsmaskinen styrer overgangene mellom å bevege armen, fylle glasset og returnere til hviletilstand, mens PID-regulatoren sørger for at fyllingen stoppes ved riktig målvekt uten søl.

Under testingen observerte vi to kontinuerlige avvik. For det første hadde armen i sjeldne tilfeller problemer med å nå posisjonene nøyaktig etter å ha beveget seg til en ny posisjon, og dette skjedde først etter lengre tids bruk. For det andre registrerte vi et konstant avvik i fyllemengden: glasset ble fylt med omtrent 12–20g vann mer enn målet av 100g. Dette skyldes at det fortsatt befinner seg vann i slangen i det øyeblikket pumpen slås av, slik at denne restmengden går ned i glasset etter at PID-regulatoren har stoppet pådraget.

13

Avviket var stabilt fra gang til gang, og kan derfor i prinsippet kompenseres for ved å justere målvekten tilsvarende ned. En til grunn for avviket kan være at Avlesningene fra HX711 chippene endret seg gradvis over tid selv uten endring i vekt.

Under testing av pumpen ble PID-verdiene justert, der Ki-verdien ble endret til 0.1. Reguleringen fungerte tilfredsstillende med denne ene endringen.

Under testingen sluttet servoen på skulderen å rotere etter å ha blitt utsatt for høyt stress. Ved nærmere undersøkelse viste det seg at de interne tannhjulene av plast var slitt ned. Servoen ble byttet ut med en servomotor med metallgir, og armen fungerte deretter som normalt.

Vi observerte også at RPi-en ga varsel om for lav strømtilførsel, og ved høyt strømtrekk oppstod det av og til ”brownout”, der RPi-en ble ustabil eller restartet. Dette inntraff særlig når servoene og pumpen var aktive samtidig. Problemet forsvant etter at de tynne, ”daisychained”-kablene ble byttet ut med kraftigere kabler koblet direkte fra strømforsyningen til hoved-PCB-en.

Sammensatt har armen fungert som tiltenkt, der alle delfunksjoner kombinert førte til den automatiske påfyllingssekvensen. I vedlegg 10 kan man se hvordan påfyllingsprosedyren foregår.

### 6. Diskusjon

Resultatene viser at systemet fungerte etter hensikten. Armen klarte å registrere når en kopp kom under den gitte terskelverdien, bevege seg til riktig posisjon og fylle koppen til eller over målnivået.

Som nevnt i resultatene var det et avvik under fylleprosessen. Avviket vurderes som akseptabelt for fylling av et glass, men kan reduseres ved å forbedre målingene fra loadcellene. En feilkilde her var drift i verdiene fra HX711, der avlesningene endret seg gradvis over tid uten endring i vekt. Denne driften er en av årsakene til det varierende avviket etter fylling. Effekten av driften kan reduseres ved jevnlig nullstilling (tare), filtrering av avlesningene gjennom median- eller gjennomsnittsmodus, og bedre skjerming av kabler for å redusere støy.

At reguleringen fungerte tilfredsstillende med så lite tuning av PID-verdiene tyder på at de valgte standardverdiene var godt egnet for systemet.

Likevel, selv om systemet nådde hensikten, var det noen svakheter og feilkilder i dette systemet.

En mekanisk svakhet var at de interne tannhjulene i servoene var laget av plast. Som beskrevet i resultatene førte dette til at servoen på skulderen sluttet å rotere etter høyt stress. Årsaken er at servoene som ble brukt ikke er dimensjonert for de kreftene armen utsettes for, noe som er en kjent svakhet ved billigere servoer med plastgir. Bytte til en servomotor med metallgir løste problemet, og er også å foretrekke på lengre sikt for å sikre armens presisjon og levetid. Det ble brukt to avkoblingskondensatorer på 5 V-skinnen fra strømforsyningen, men lokal avkobling ved hver enkelt servo kunne potensielt redusert spenningstransienter ytterligere under høy belastning. Dette ble ikke testet, og er derfor kun en mulig forbedring.

Problemet med ”brownout” på RPi-en skyldtes ikke selve strømforsyningen, men ledningene mellom strømforsyningen og hoved-PCB-en. Opprinnelig var det brukt tynne kabler som var ”daisychained” videre til kortet, noe som ga for stort spenningsfall ved høyt strømtrekk, særlig når servoene og pumpen var aktive samtidig. En ”brownout” kan føre til ustabil oppførsel eller at Pi-en restarter. Problemet ble løst ved å bytte til kraftigere kabler koblet direkte fra strømforsyningen til hoved-PCB-en. Dette reduserte spenningsfallet, og strømforsyningen leverte deretter stabil spenning også under høy belastning.

De tre feilene som ble oppdaget på hoved-IO-kortet lot seg fikse med loddebroer og kabling, og bør rettes opp i designet i en eventuell ny revisjon av kortet.

14

Noen tekniske valg ble gjort under dette prosjektet. Det ble valgt å bruke en egen PSU i stedet for en laboratorie strømforsyningen. Dette var fordi at systemet hadde behov for en strømforsyning som kunne levere nok amper til alle komponentene samtidig (kan se i POR-vedlegget). Det som er beskrevet over viste det seg likevel at strømforsyningen ikke var godt nok dimensjonert noe som førte til ”brownout” ved høyt strømtrekk. Varselmeldingen på RPi-en om at det var for lite strøm kan være fordi PSU-en leverte 4,9V i stedet for 5V eller helst 5,1 V til RPi-en. Dette valget bør derfor revurderes med tanke på en annen PSU.

For å styre pumpen med PWM-signaler ble det valgt å bruke en ekstern modul (L298N) i stedet for å integrere H-broen direkte på PCB-en. Dette var fordi det begynte å bli lite plass igjen på PCB-en til alle funksjonene, og for å redusere risikoen for at hovedfunksjonen: å styre pumpen med PWM, ikke skulle fungere. Ved å legge pumpestyringen i en egen modul ble designet enklere og sjansen for feil på selve kortet redusert.

Samlet sett fungerte systemet etter hensikten. Pumpestyringen med PID-regulering ga presis fylling med kun et lite avvik, og robotarmen klarte å bevege seg mellom de forhåndsdefinerte posisjonene som planlagt. Svakhetene som ble avdekket lot seg alle utbedre underveis, og påvirket ikke det endelige resultatet.

### 7. Konklusjon

I dette prosjektet ble det laget en automatisk refill arm som fyller glass med væske når en vektsensor registrerer at de er tomme. Systemet ble bygget opp av en Raspberry Pi med egendesignede PCB-er, 3D-printede deler og øvrige elektronikkomponenter, og programvare som håndterer PID-regulering og invers kinematikk.

Prosjektet nådde hovedmålet sitt. Den ferdige armen klarte å registrere tomme kopper, bevege seg til riktig posisjon og fylle dem med et avvik på omtrent 10 g, noe som vurderes som tilstrekkelig presist for formålet.

For videre arbeid bør de tre feilene som ble oppdaget under testing — manglende jording av OE-pinnen på PCA9685, ombyttede I2C-pinner, og manglende styringspinne for pumpen — rettes direkte i designet i en ny revisjon av kortet, slik at de ikke lenger må utbedres med loddebroer og kabling. Videre bør servoene byttes ut med motorer med metallgir i stedet for plastgir for å gjøre armen mer robust. På lengre sikt kan systemet integreres med trådløs kommunikasjon mellom lastcellene og RPi-en, noe som ville gjort oppsettet mer fleksibelt og redusert behovet for kabling.

Et naturlig neste steg ville være å ta invers kinematikk fullt i bruk. I stedet for å lagre leddvinkler på forhånd kunne hvert glass hatt sine egne koordinater, og en IMU kunne registrert om glassene flyttes. På denne måten slipper man å lagre en posisjon manuelt for hver vektcelle, og systemet blir mer dynamisk. Slik koden fungerer nå, er IK i praksis redundant og fungerer mer som en ekstrafunksjon enn en nødvendig del av systemet.

15

### 8. Kildehenvisning

Cults3D. (u.å.). Arduino based robot arm – HowToMechatronics [3D modell]. Hentet 26. mai 2026 fra https: //cults3d.com/en/3d-model/various/arduino-based-robot-arm-howtomechatronics

Vendelator. (u.å.). Load Cell Scale Mount [3D modell]. Printables. Hentet 26. mai 2025 fra https://www.printables.com/model/374800-load-cell-scale-mount

Handson Technology. (u.å.). L298N dual H-bridge motor driver [Datablad]. Hentet 26. mai 2026 fra https: //www.handsontec.com/dataspecs/L298N%20Motor%20Driver.pdf

NXP Semiconductors. (2015). PCA9685: 16-channel, 12-bit PWM Fm+ I²C-bus LED controller [Datablad]. https://www.nxp.com/docs/en/data-sheet/PCA9685.pdf

SparkFun Electronics. (u.å.). HX711: 24-bit analog-to-digital converter (ADC) for weigh scales [Datablad]. Hentet 26. mai 2026 fra https://cdn.sparkfun.com/datasheets/Sensors/ForceFlex/hx711_en glish.pdf (https://cdn.sparkfun.com/datasheets/Sensors/ForceFlex/hx711_english.pdf)

Wikipedia. (u.å.). Inverse kinematics. Hentet 26. mai 2026 fra https://en.wikipedia.org/wiki/Inverse_kinematics (https://en.wikipedia.org/wiki/Inverse_kinematics)

Ogawa, T. & Kanada, H. (2010). Inverse kinematics problem of 3-DOF robot arm in 2D plane [Figur og Invers kinematik]. I Solution for Ill-Posed Inverse Kinematics of Robot Arm by Network Inversion. ResearchGate. https://www.researchgate.net/figure/Inverse-kinematics-problem-of-3-DOF-robot-arm-in-2D-plane-a-Three-joints-and-an_fig3_46401997 (https://www.researchgate.net/figure/Inverse-kinematics-problem-of-3-DOF-robot-arm-in-2D-plane-a-Three-joints-and-an_fig3_46401997)

16

### 9. Vedlegg

Vedlegg 10: Se vedlegg mappe for videoen

Figur 11: Deployment Diagram

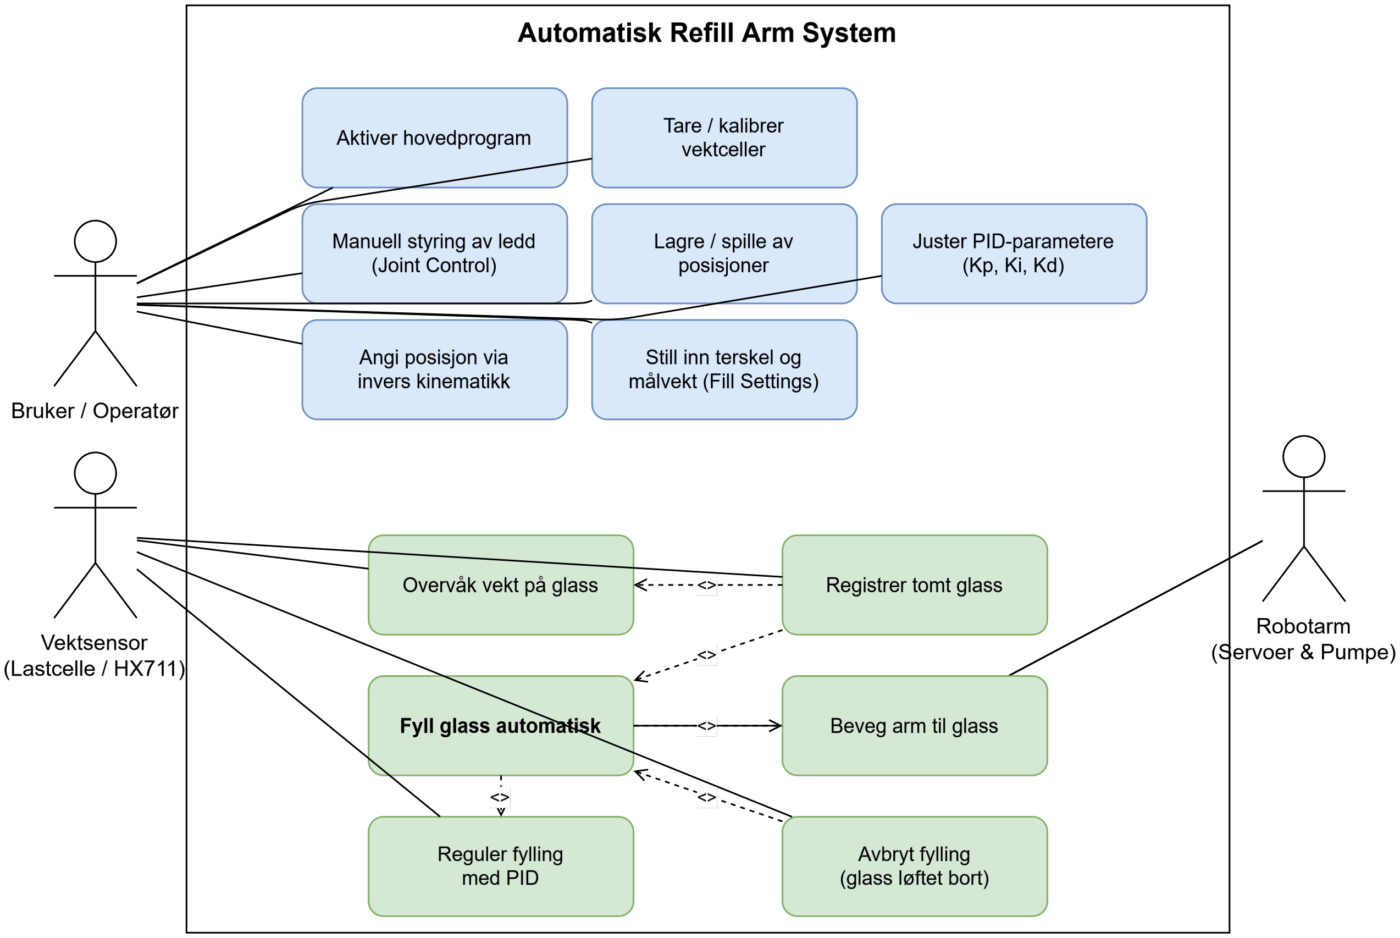
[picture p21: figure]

Figur 12: Use-Case Diagram

17

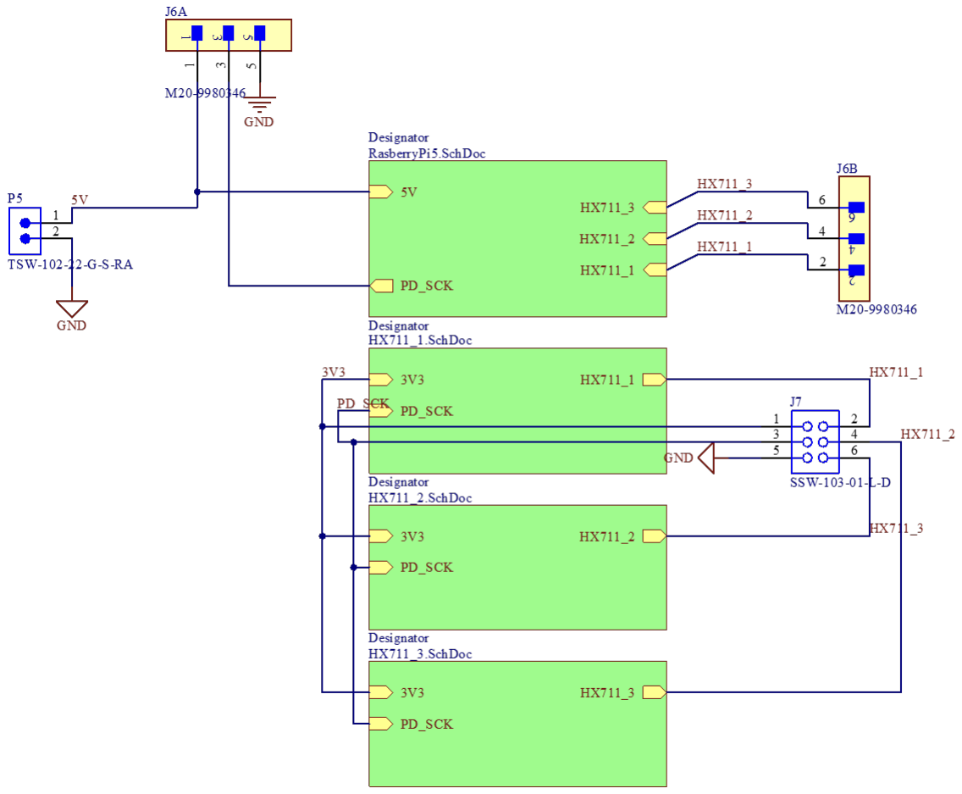
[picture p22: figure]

Figur 13: Hoved kretskjema der alle individe komponenter ble satt sammen.

18

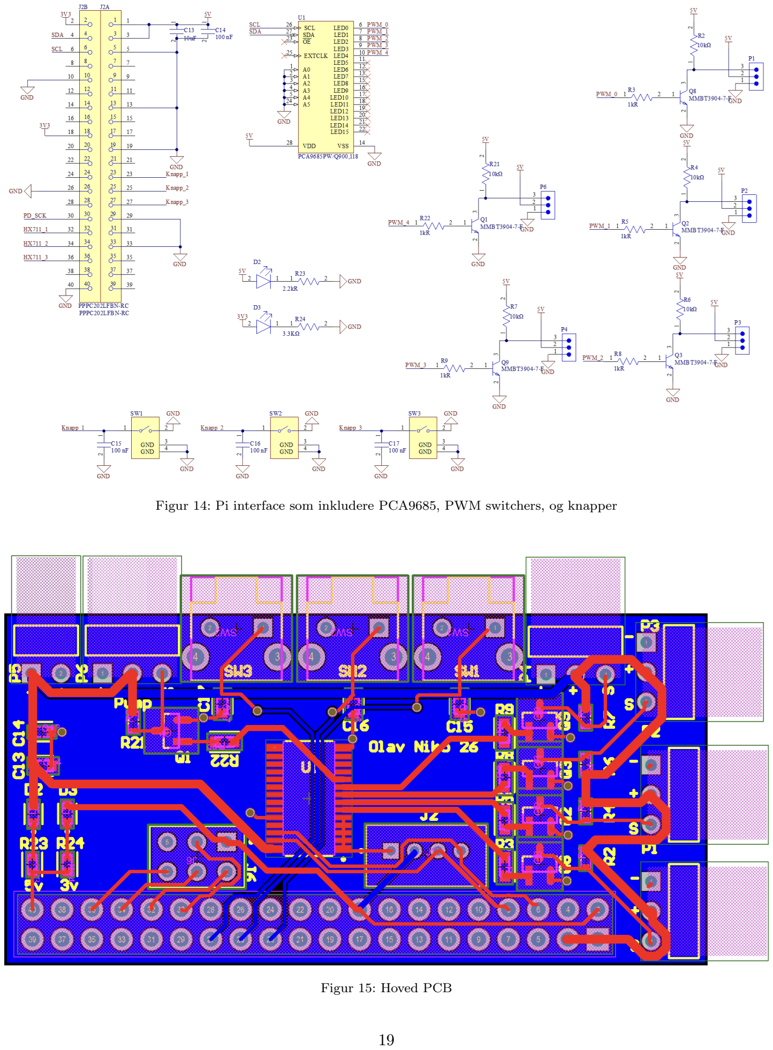
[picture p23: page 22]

Figur 14: Pi interface som inkludere PCA9685, PWM switchers, og knapper

Figur 15: Hoved PCB

19

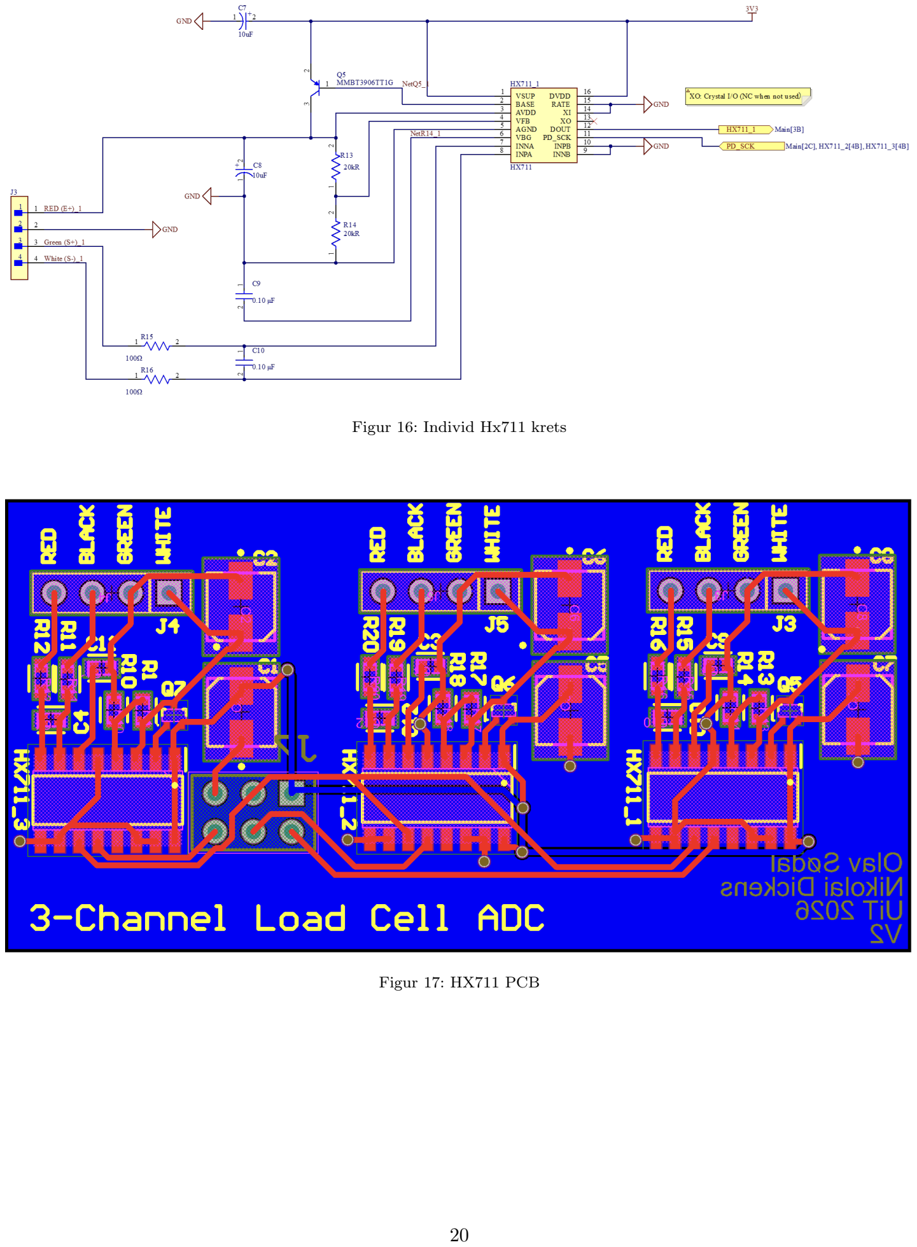
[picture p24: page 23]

Figur 16: Individ Hx711 krets

Figur 17: HX711 PCB

20

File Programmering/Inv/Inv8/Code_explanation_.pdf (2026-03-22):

# Kodeforklaring

## Olav Arnold

## Mars 2026

## 1 Introduksjon

### Dette dokumentet forklarer de viktigste delene av en Python GUI-applikasjon

som styrer et IO-kort over en serietilkobling. Det dekker seriekommunikasjon, LED-styring, sensoravlesning, servo, summer og logging.

## 2 Serieport

### Denne koden kobler til AVR-en og dobbeltsjekker at den er tilkoblet og svarer

korrekt.

1 | PORT | = ’/dev / ttyAMA0 ’
2 | BAUD | = 38400

3
4 ser = None

5
6 | def connect_serial () :
7 | global ser
8 | try :
9 | ser = serial . Serial ( PORT , BAUD , timeout =2)
10 | time . sleep (0.5)
11 | log ( f" Tilkoblet { PORT } @ { BAUD }")
12 | except Exception as e :
13 | log ( f"[ FEIL ] Kan ikke apne { PORT }: {e}")

14
15 | def send_command ( cmd : str ) -> str :
16 | if ser is None or not ser . is_open :
17 | log ( f"[ IKKE TILKOBLET ] {cmd }")
18 | return ""
19 | try :
20 | ser . write (( cmd + ’\n’) . encode () )
21 | response = ser . readline () . decode () . strip ()
22 | log ( f" >>> {cmd } | <<< { response }")
23 | return response
24 | except Exception as e :
25 | log ( f"[ FEIL ] {e}")

1

26 | return ""

### Listing 1: Serietilkobling og kommandfunksjon

## 3 LED-klassen

### Koden nedenfor viser class LED, hvor @property er brukt. @property er en innebygd dekorator i Python som lar deg lage en metode som oppfører seg som

et attributt, noe som gjør koden finere.

1 | class LED :
2 | # Representerer en LED pa IO - kortet med pa/av - tilstand .
3 | def __init__ ( self , index : int) :
4 | self . index = index | # 0 -3
5 | self . _state = False | # False = av , True = pa

6
7 | @property
8 | def state ( self ) -> bool :
9 | return self . _state

10
11 | def turn_on ( self ) :
12 | if not self . _state :
13 | resp = send_command ( f"LED :{ self . index }")
14 | if resp == "OK":
15 | self . _state = True

16
17 | def turn_off ( self ) :
18 | if self . _state :
19 | resp = send_command ( f"LED :{ self . index }")
20 | if resp == "OK":
21 | self . _state = False

22
23 | def toggle ( self ) :
24 | if self . _state :
25 | self . turn_off ()
26 | else :
27 | self . turn_on ()

### Listing 2: Implementasjon av LED-klassen

## 4 Loggfunksjon

### Koden nedenfor skriver ut i terminalen, som gjør det enklere ˚a vise hvilken

melding som blir sendt ut.

1 _log_widget = None

2

2

3 | def log ( msg : str ) :
4 | print ( msg )

### Listing 3: Logg-funksjon

## 5 Sensoravlesning – hjelpefunksjon

### poll sensor() sender en kommando til maskinen og oppdaterer en etikett i GUIen med svaret. Den kjører i en bakgrunnen slik at GUIen ikke frys mens

den venter p˚a svar fra sensoren.

1 | def poll_sensor ( cmd : str , label : tk . Label , prefix : str) :
2 | def task () :
3 | resp = send_command ( cmd )
4 | label . config ( text = f"{ prefix }{ resp }")
5 | threading . Thread ( target = task , daemon = True ) . start ()

### Listing 4: Hjelpefunksjon for sensoravlesning i bakgrunnstrad

## 6 Sensorseksjon

### Dette er et enkelt GUI for ˚a vise ADC- og temperaturverdier etter at knappen

for den de enkelte sensorene er trykket.

1 | adc_label = tk . Label ( sens_frame , text =" ADC: -", font =("
| Courier ", 11) ,
2 | anchor ="w", width =28)
3 | adc_label . pack ( anchor ="w")
4 | tk . Button ( sens_frame , text =" Les ADC",
5 | command = lambda : poll_sensor (" ADC", adc_label , " ADC
| : ")
6 | ) . pack ( anchor ="w", pady =(2 , 6) )

7
8 | tmp_label = tk . Label ( sens_frame , text =" Temperatur : -", font
| =(" Courier ", 11) ,
9 | anchor ="w", width =28)
10 | tmp_label . pack ( anchor ="w")
11 | tk . Button ( sens_frame , text ="Les temperatur ",
12 | command = lambda : poll_sensor ("TMP ", tmp_label , "
| Temperatur : ")
13 | ) . pack ( anchor ="w", pady =2)

### Listing 5: GUI for ADC- og temperatursensor

3

## 7 Servoseksjon

### En glidebryter for servoen som sender den oppdaterte verdien til servomotoren

n˚ar den bevages.

1 | servo_label = tk . Label ( servo_frame , text =" Vinkel : 90", font
| =(" Segoe UI", 10) )
2 | servo_label . pack ()

3
4 | def on_servo_change ( val ) :
5 | angle = int ( float ( val ) )
6 | servo_label . config ( text = f" Vinkel : { angle }")
7 | send_command ( f" SERVO :{ angle }")

8
9 | servo_scale = tk . Scale ( servo_frame , from_ =0 , to =180 ,
10 | orient = tk . HORIZONTAL , length =200 ,
11 | command = on_servo_change )
12 | servo_scale .set (90)
13 | servo_scale . pack ()

### Listing 6: GUI for servoglidebryter

## 8 Alle p˚a / alle av

### De to første linjene oppretter rammen for GUI-kontrollene. Funksjonene all on() og all off() sender kommandoer for ˚a sl˚a alle LED-er p˚a og av, med en liten forsinkelse mellom hver LED slik at de ikke føkke opp hverandre. De to siste

linjene er knappene for dette.

1 | ctrl_row = tk . Frame ( led_frame )
2 | ctrl_row . pack ( pady =(8 , 0) )

3
4 | def all_on () :
5 | def task () :
6 | for i in range (4) :
7 | leds [ i ]. turn_on ()
8 | root . after (0 , refresh_led , i )
9 | time . sleep (0.1)
10 | threading . Thread ( target = task , daemon = True ) . start ()

11
12 | def all_off () :
13 | def task () :
14 | for i in range (4) :
15 | leds [ i ]. turn_off ()
16 | root . after (0 , refresh_led , i )
17 | time . sleep (0.1)
18 | threading . Thread ( target = task , daemon = True ) . start ()

19

4

20 | tk . Button ( ctrl_row , text =" Alle PA", | width =10 , command =
all_on ) . pack ( side = tk . LEFT , padx =4)
21 tk . Button ( ctrl_row , text =" Alle AV", width =10 , command = all_off ) . pack ( side = tk . LEFT , padx =4)

### Listing 7: Knapper og logikk for a styre alle LED-er samtidig

## 9 Buzzer seksjon

### Dette er ogs˚a en glidebryter, men den sender kun frekvensverdien til buzzeren

n˚ar avspillingsknappen trykkes, ikke for hver bevegelse.

1 | buzz_label = tk . Label ( buzz_frame , text =" Frekvens : 500 Hz",
| font =(" Segoe UI", 10) )
2 | buzz_label . pack ()

3
4 | def on_buzz_change ( val ) :
5 | freq = int ( float ( val ) )
6 | buzz_label . config ( text = f" Frekvens : { freq } Hz")

7
8 | buzz_scale = tk . Scale ( buzz_frame , from_ =0 , to =4000 ,
9 | orient = tk . HORIZONTAL , length =200 ,
10 | command = on_buzz_change )
11 | buzz_scale .set (500)
12 | buzz_scale . pack ()

13
14 | btn_row = tk . Frame ( buzz_frame )
15 | btn_row . pack ( pady =4)

16
17 | def send_buzz () :
18 | freq = buzz_scale . get ()
19 | send_command ( f" BUZZ :{ freq }")

20
21 | def stop_buzz () :
22 | buzz_scale .set (0)
23 | send_command (" BUZZ :0")

24
25 tk . Button ( btn_row , text =" Spill av", command = send_buzz , width =10) . pack ( side = tk . LEFT , padx =3)
26 | tk . Button ( btn_row , text =" Stopp ", | command = stop_buzz ,
width =10) . pack ( side = tk . LEFT , padx =3)

### Listing 8: GUI for summer

5

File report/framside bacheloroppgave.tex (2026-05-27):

\thispagestyle{empty}
%\enlargethispage{1in}
\vspace*{-2in}
\vspace*{15pt}
\hspace*{-0.7in}
{\bf Fakultet for ingeniørvitenskap og teknologi}\\
\vspace{15pt}
{\large AUT-2606 Semester Prosjekt: Rapport}\\
\vspace{15pt}
{\Large \bf Automatisk refill arm}\\
\vspace{15pt}
\begin{tabularx}{\textwidth} { 
   >{\raggedright\arraybackslash}X 
   >{\raggedleft\arraybackslash}X
   >{\raggedleft\arraybackslash}X  }
 \hline
 Olav A. Sødal  & Nikolai A. Dickens \\
 olsod5888@uit.no   & nidic4105@uit.no  \\
\hline
\end{tabularx}
\vspace{15pt}\\
{Institutt for Automasjon og Prosessteknologi}\\
{\small \bf dato årstall}
\vspace{15pt}

%fremsidebilde
\begin{figure}[h]
\centerline{}
\end{figure}
\vfill

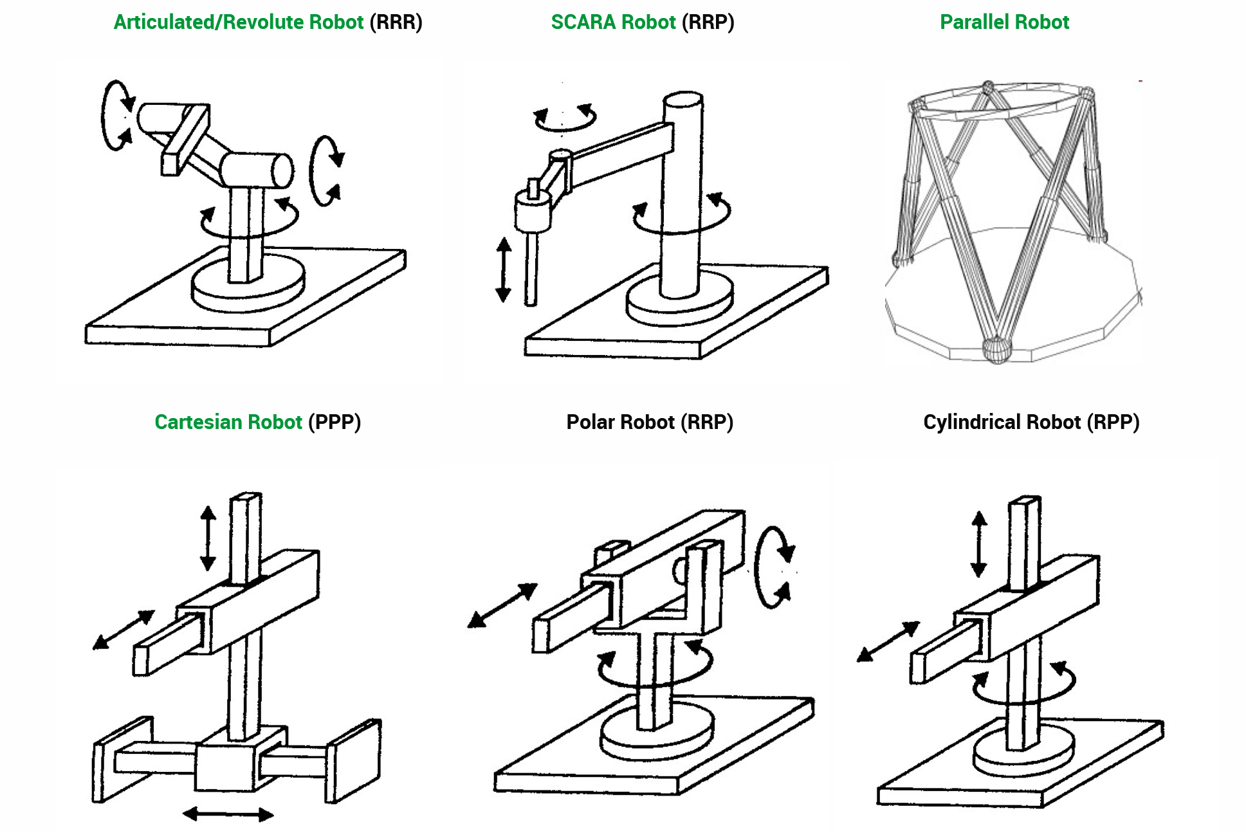
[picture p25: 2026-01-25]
report/Images/ArmTyper.png

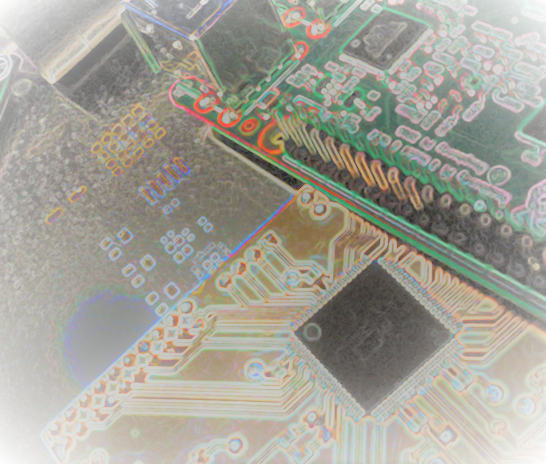
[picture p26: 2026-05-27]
report/Images/Lab-hefte.png

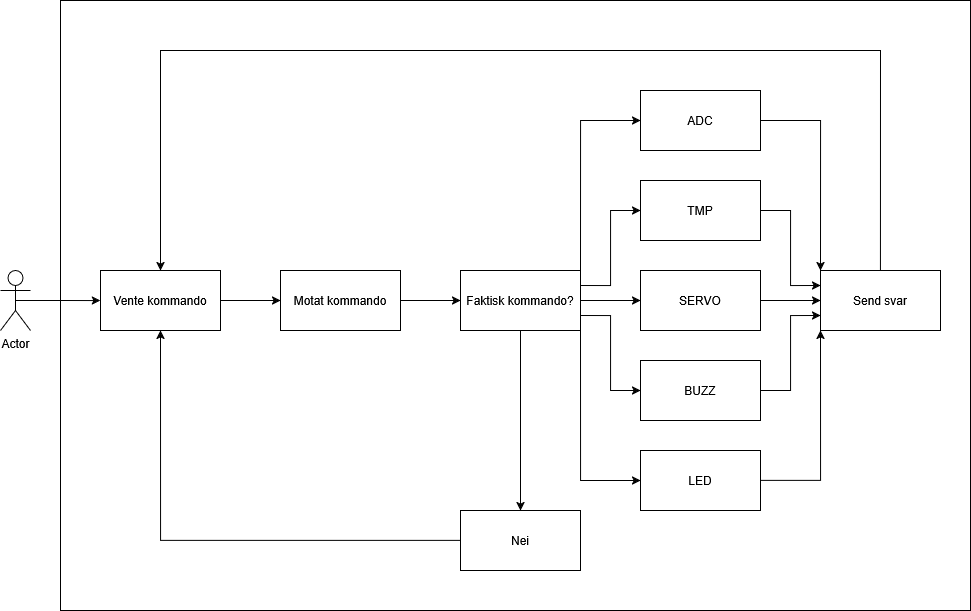
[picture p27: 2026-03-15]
Programmering/Inv/Inv7/Untitled Diagram.drawio.png

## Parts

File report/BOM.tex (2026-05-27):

\newcolumntype{P}[1]{>{\raggedright\arraybackslash}p{#1}}

\begin{center}
\footnotesize
\begin{longtable}{P{4.6cm} P{2.6cm} P{3.4cm} P{2.0cm} c}
\caption{Komponentliste (BOM) for PCB-ene.}\label{tab:bom}\\
\hline
\textbf{Description} & \textbf{Designator} & \textbf{Mfr. Part Number} & \textbf{Supplier} & \textbf{Qty} \\
\hline
\endfirsthead
\hline
\textbf{Description} & \textbf{Designator} & \textbf{Mfr. Part Number} & \textbf{Supplier} & \textbf{Qty} \\
\hline
\endhead
\hline
\endfoot
CAP ALUM 10UF 20\% 35V SMD & C1, C2, C5, C6, C7, C8 & EDK106M035A9BAA & Farnell & 6 \\
CAP CER 0.1UF 25V X7R 0603 & C3, C4, C9, C10, C11, C12 & C0603C104K3RAC7411 & Mouser & 6 \\
CAP CER 10UF 10V X5R 0603 & C13 & GRM188R61A106KE69D & Arrow & 1 \\
CC0603 100\,nF X7R 10\% 25\,V & C14, C15, C16, C17 & CC0603KPX7R8BB104 & Mouser & 4 \\
LED GREEN CLEAR CHIP SMD & D2, D3 & LTST-C193KGKT-5A & DigiKey & 2 \\
Female header, 40C, straight, 2.54\,mm, PBT/phos bronze & J2 & PPPC202LFBN-RC & DigiKey & 1 \\
CONN HEADER VERT 4POS 2.54MM & J3, J4, J5 & TSW-104-23-T-S & Arrow & 3 \\
CONN HEADER VERT 6POS 2.54MM & J6 & M20-9980346 & DigiKey & 1 \\
SQ post socket, TH, vertical, 2.54\,mm, 6-pin, female & J7 & SSW-103-01-L-D & DigiKey & 1 \\
0.025" SQ post header, TH, right-angle, 2.54\,mm, 2-pin, male & P5 & TSW-102-22-G-S-RA & Arrow & 1 \\
TRANS NPN 40V 0.2A SMD SOT23-3 & Q1, Q2, Q3, Q8, Q9 & MMBT3904-7-F & Farnell & 5 \\
Transistor PNP, 3-pin SC-75, Pb-free & Q5, Q6, Q7 & MMBT3906TT1G & Mouser & 3 \\
RES thick film, 20\,k$\Omega$, 1\%, 0.33\,W, 0603 & R1, R10, R13, R14, R17, R18 & CRCW060320K0FKEAHP & Arrow & 6 \\
RES thick film, 10\,k$\Omega$, 1\%, 0.2\,W, 0603, AEC-Q200 & R2, R4, R6, R7, R21 & SG73P1JTTD1002F & Mouser & 5 \\
RES thick film, 1\,k$\Omega$, 1\%, 0.1\,W, 0603, AEC-Q200 & R3, R5, R8, R9, R22 & RK73G1JTTD1001F & Farnell & 5 \\
RES SMD 100\,$\Omega$ 1\% 1/10W 0603 & R11, R12, R15, R16, R19, R20 & RT0603FRE07100RL & Arrow & 6 \\
RES thick film, 2.2\,k$\Omega$, 5\%, 0.1\,W, 0603 & R23 & RC1608J222CS & Arrow & 1 \\
RES thick film, 3.3\,k$\Omega$, 5\%, 0603 & R24 & CRGCQ0603J3K3 & Arrow & 1 \\
SWITCH TACTILE SPST-NO 0.05A 24V & SW1, SW2, SW3 & B3F-3122 & Arrow & 3 \\
\end{longtable}
\end{center}

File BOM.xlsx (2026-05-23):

Description | Designator | Manufacture Part Number | Supplier | Quantity
Description | Designator | Manufacturer Part Number 1 | Supplier 1 | Quantity
CAP ALUM 10UF 20% 35V SMD | C1, C2, C5, C6, C7, C8 | EDK106M035A9BAA | Farnell | 6
CAP CER 0.1UF 25V X7R 0603 | C3, C4, C9, C10, C11, C12 | C0603C104K3RAC7411 | Mouser | 6
CAP CER 10UF 10V X5R 0603 | C13 | GRM188R61A106KE69D | Arrow Electronics | 1
CC0603 100 nF X7R 10.00% 25 V | C14, C15, C16, C17 | CC0603KPX7R8BB104 | Mouser | 4
LED GREEN CLEAR CHIP SMD | D2, D3 | LTST-C193KGKT-5A | DigiKey | 2
PPPC202LFBN-RC Female, 40C, Straight, .100"CC; 3.20mm Tail, No Mt.; PBT, Phos Bronze, 105 C | J2 | PPPC202LFBN-RC | DigiKey | 1
CONN HEADER VERT 4POS 2.54MM | J3, J4, J5 | TSW-104-23-T-S | Arrow Electronics | 3
CONN HEADER VERT 6POS 2.54MM | J6 | M20-9980346 | DigiKey | 1
SQ Post Socket, Through-hole, Vertical, -55 to 125 degC, 2.54 mm Pitch, 6-Pin, Female, RoHS | J7 | SSW-103-01-L-D | DigiKey | 1
0.025" SQ Post Header, Through-hole, Right Angle, -55 to 125 degC, 2.54 mm Pitch, 2-Pin, Male, RoHS | P5 | TSW-102-22-G-S-RA | Arrow Electronics | 1
TRANS NPN 40V 0.2A SMD SOT23-3 | Q1, Q2, Q3, Q8, Q9 | MMBT3904-7-F | Farnell | 5
General Purpose Transistor, PNP Silicon, 3-Pin SC-75, Pb-Free, Tape and Reel | Q5, Q6, Q7 | MMBT3906TT1G | Mouser | 3
RES Thick Film, 20kΩ, 1%, 0.33W, 100ppm/°C, 0603 | R1, R10, R13, R14, R17, R18 | CRCW060320K0FKEAHP | Arrow Electronics | 6
SG73P1JTTD1002F Res Thick Film 0603 10K Ohm 1% 0.2W(1/5W) ±100ppm/C Pad SMD Automotive T/R | R2, R4, R6, R7, R21 | SG73P1JTTD1002F | Mouser | 5
1kΩ ±1% 0.1W Chip Resistor 0603 Thick Film AEC-Q200 Qualified | R3, R5, R8, R9, R22 | RK73G1JTTD1001F | Farnell | 5
RES SMD 100 OHM 1% 1/10W 0603 | R11, R12, R15, R16, R19, R20 | RT0603FRE07100RL | Arrow Electronics | 6
Res Thick Film 0603 2.2kΩ 5% 0.1W ±100ppm/°C Molded SMD T/R | R23 | RC1608J222CS | Arrow Electronics | 1
CRGCQ 0603 3K3 5% | R24 | CRGCQ0603J3K3 | Arrow Electronics | 1
SWITCH TACTILE SPST-NO 0.05A 24V | SW1, SW2, SW3 | B3F-3122 | Arrow Electronics | 3

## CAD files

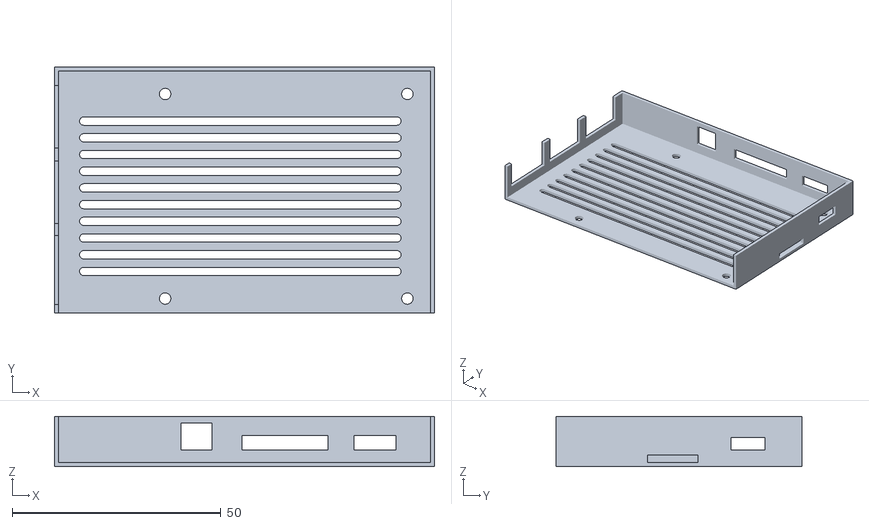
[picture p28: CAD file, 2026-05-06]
CAD/PiCaseV4_Base_wHoles.stl
91.0 x 59.0 x 12.0

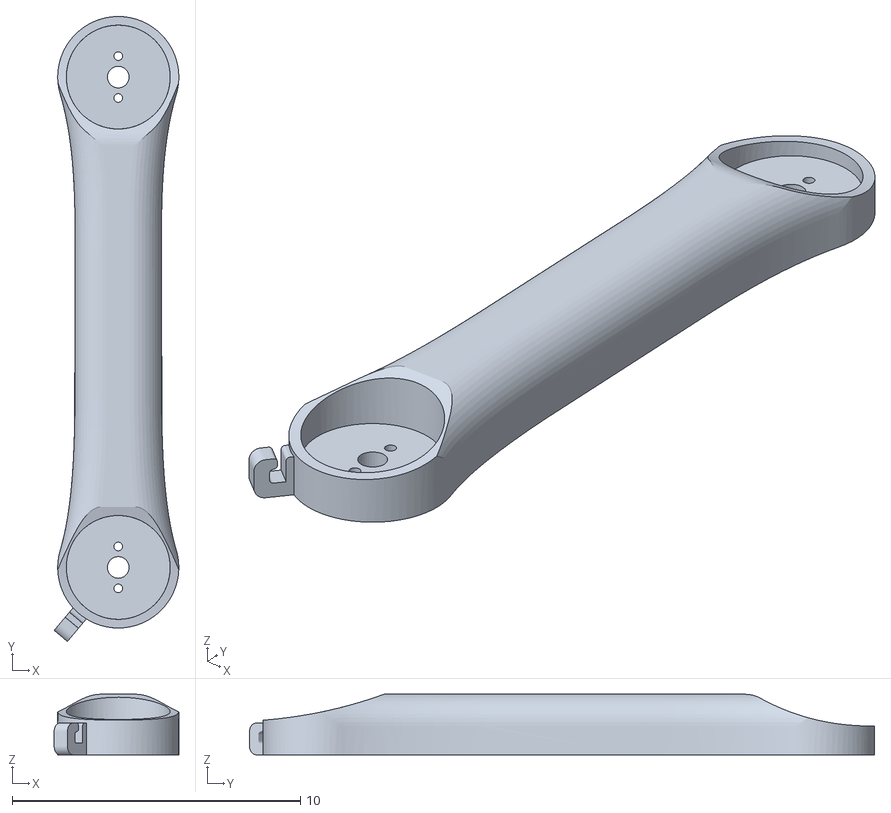
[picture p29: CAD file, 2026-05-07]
CAD/Arduino Robot Arm - STL Files/Arm_01_5cm_woHole.STL
4.32 x 21.7 x 2.10

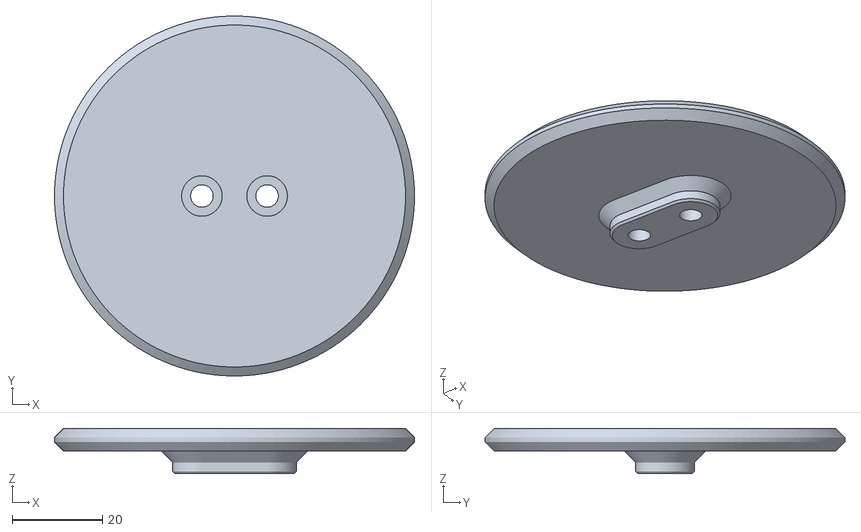
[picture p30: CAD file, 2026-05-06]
CAD/load-cell-scale-mount-model_files/HX711_Load_Cell--Scale.stl
80.0 x 80.0 x 10.0

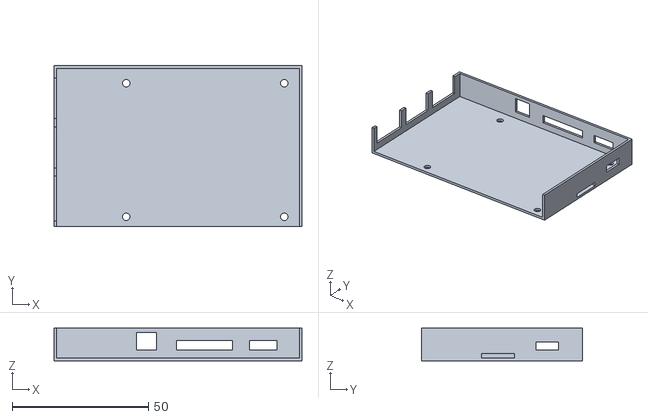
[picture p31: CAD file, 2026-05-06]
CAD/PiCaseV4_Base.stl
91.0 x 59.0 x 12.0

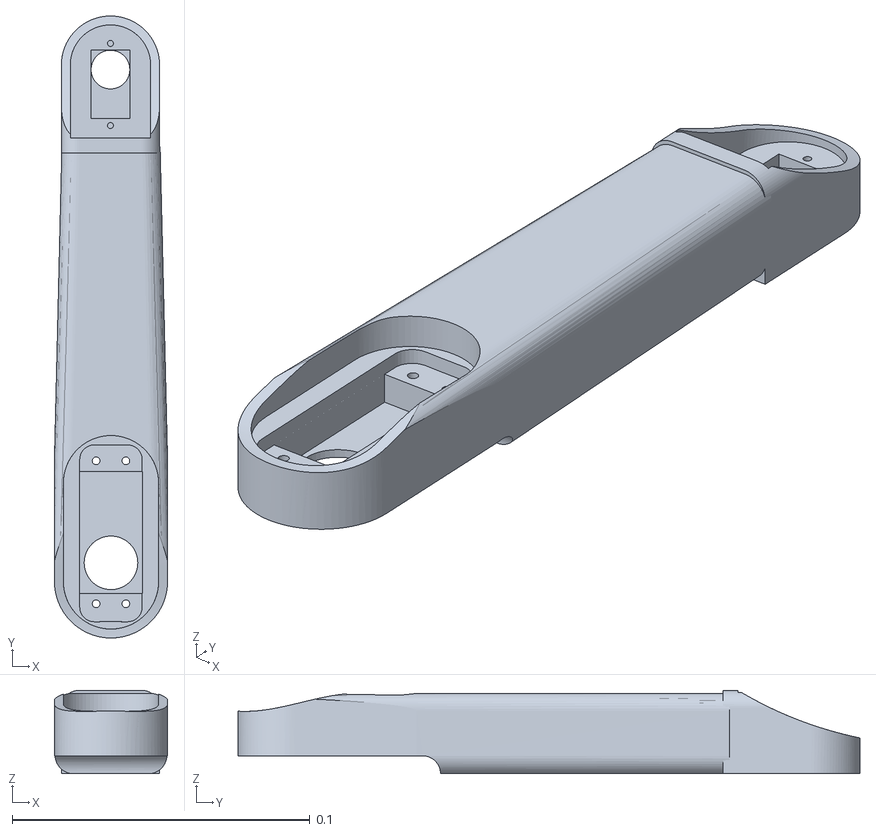
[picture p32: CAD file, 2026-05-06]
CAD/Arduino Robot Arm - STL Files/SammenSettArm2_fiks_50mm_woHole.STL
0.038 x 0.209 x 0.028

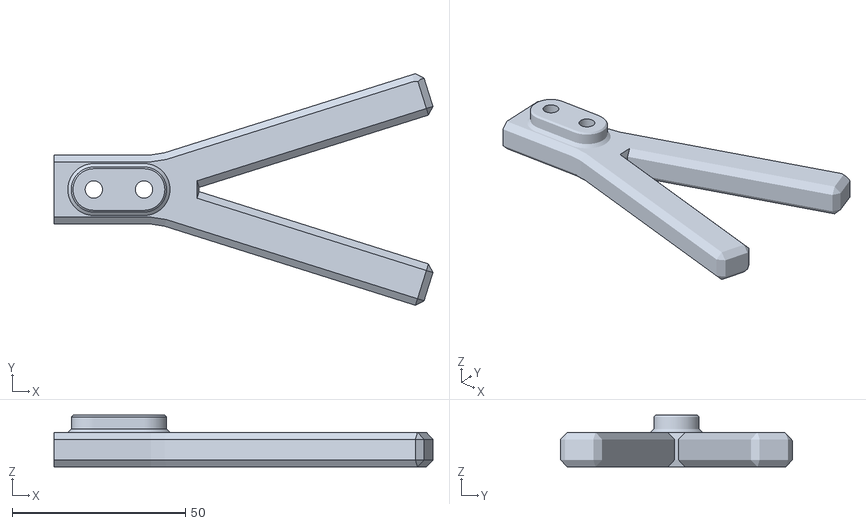
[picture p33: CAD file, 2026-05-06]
CAD/load-cell-scale-mount-model_files/HX711_Load_Cell--Foot.stl
109.5 x 66.9 x 15.0

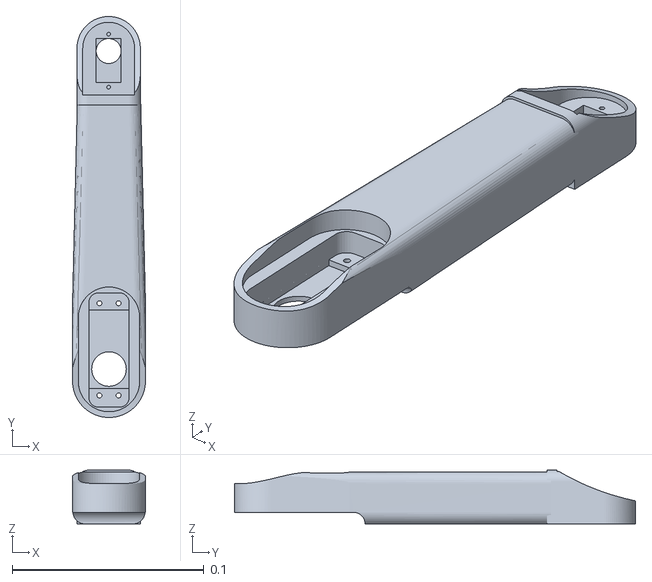
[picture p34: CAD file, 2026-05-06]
CAD/Arduino Robot Arm - STL Files/SammenSettArm2_50mm_woHole.STL
0.038 x 0.209 x 0.028

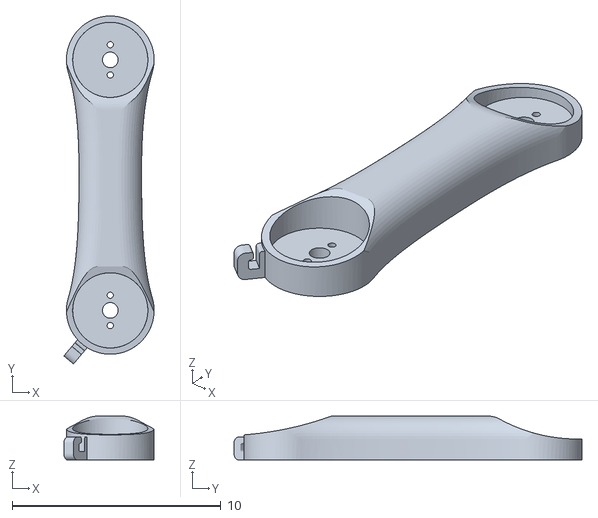
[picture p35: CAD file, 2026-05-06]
CAD/Arduino Robot Arm - STL Files/Arm_01_woHole.STL
4.32 x 16.7 x 2.10

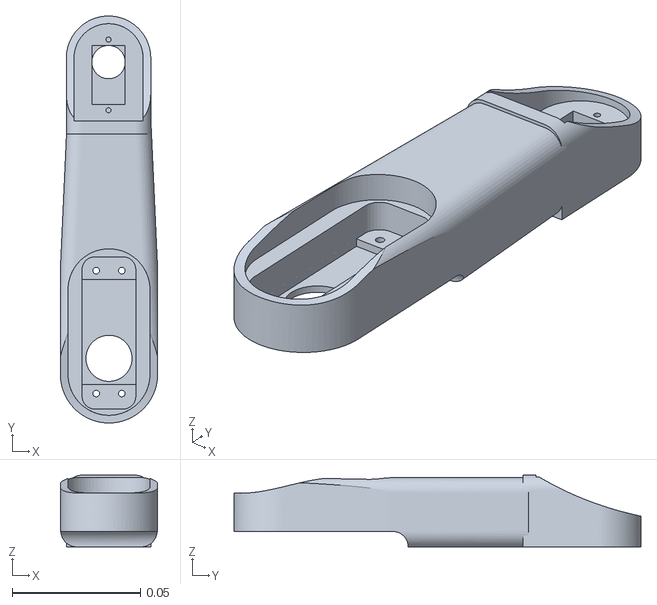
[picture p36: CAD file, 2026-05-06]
CAD/Arduino Robot Arm - STL Files/SammenSettArm2_ORG_woHole.STL
0.038 x 0.159 x 0.028

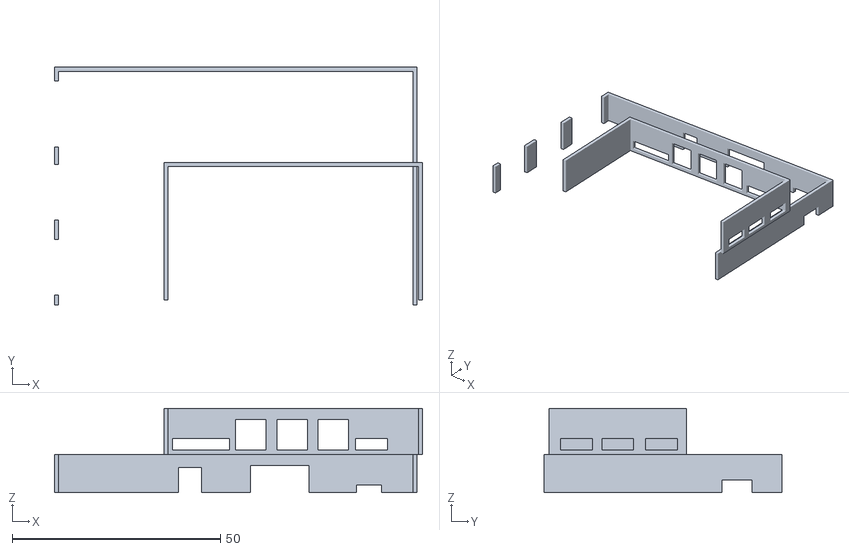
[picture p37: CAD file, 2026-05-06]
CAD/PiCaseV1.3.stl
88.3 x 57.0 x 20.2

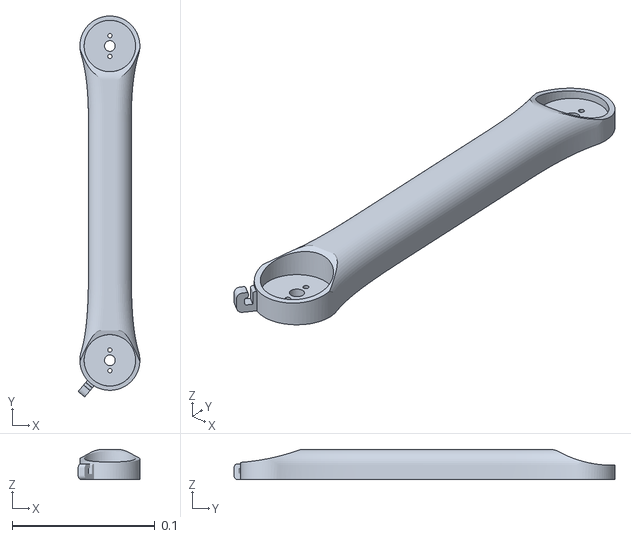
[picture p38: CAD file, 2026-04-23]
CAD/Arduino Robot Arm - STL Files/Arm_01_10cm_woHole.STL
0.0432 x 0.267 x 0.021

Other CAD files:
CAD/gcode/Arm_01_5cm+ORG_woHole.gcode.3mf
CAD/gcode/Arm2OGwrist_v2.gcode.3mf
CAD/gcode/HX711_Load_Cell.gcode.3mf
CAD/gcode/PiCase4+loadcells.gcode.3mf
CAD/Arduino Robot Arm - STL Files/SammenSettArm2_fiks_ORG_woHole.STL
CAD/gcode/ssd1306_Cases.gcode.3mf
CAD/gcode/PiCaseV4.gcode.3mf
CAD/Arduino Robot Arm - STL Files/Arm 01.STL
CAD/Arduino Robot Arm - STL Files/Arm 02 v3.STL
CAD/Arduino Robot Arm - STL Files/Arm 03.STL
CAD/Arduino Robot Arm - STL Files/Arm_01_10cm.STL
CAD/Arduino Robot Arm - STL Files/Arm_02_fiks.STL
CAD/Arduino Robot Arm - STL Files/Arm_02_fiks_10cm.STL
CAD/Arduino Robot Arm - STL Files/Base.STL
CAD/Arduino Robot Arm - STL Files/Gripper 1.STL
CAD/Arduino Robot Arm - STL Files/Gripper base.STL
CAD/Arduino Robot Arm - STL Files/SammenSettArm2.stl
CAD/Arduino Robot Arm - STL Files/SammenSettArm2_woHole.stl
CAD/Arduino Robot Arm - STL Files/Waist.STL
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

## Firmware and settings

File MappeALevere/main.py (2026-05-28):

from tkinter import *
from tkinter import ttk
from adafruit_servokit import ServoKit
import time
import math
import hx711

from gpiozero import OutputDevice
from gpiozero import Button as GPIOButton
pump_fwd = OutputDevice(21, initial_value=False)

kit = ServoKit(channels=16)

def drive(midje, skulder, albue, wrist, pump):
    min = 2350
    max = 5650

    def angle_to_us(deg):
        return int(max - ((max - min) * (deg / 90)))

    kit._pca.channels[0].duty_cycle = 65535 - angle_to_us(midje)
    kit._pca.channels[1].duty_cycle = 65535 - angle_to_us(skulder)
    kit._pca.channels[2].duty_cycle = 65535 - angle_to_us(albue)
    kit._pca.channels[3].duty_cycle = 65535 - angle_to_us(wrist)
    
    desired_duty = int(pump / 100 * 65535)
    kit._pca.channels[4].duty_cycle = 65535 - desired_duty
 
#state machine
activate     = False
fill_state  = "idle"   # idle / moving / filling

#arm dimetions (cm)
L1     = 15.0   # arm_1
L2     = 15.0   # arm_2
L3     = 5.0    # wrist
Z_BASE =  5.0   # base height

#servo angle offsets (deg)
MOUNT_SKULDER = 45.0 
MOUNT_ALBUE   =  0.0
MOUNT_WRIST   =  0.0

def solve_ik(x, y, z, phi_deg, elbow_up=True):
    phi = math.radians(phi_deg)

    #base rotation
    theta_base = math.atan2(y, x)
    r = math.hypot(x, y)

    #wrist point in planar
    xw = r - L3 * math.cos(phi)
    yw = (z - Z_BASE) - L3 * math.sin(phi)

    #albue
    cos_t2 = (xw**2 + yw**2 - L1**2 - L2**2) / (2 * L1 * L2)
    cos_t2 = max(-1.0, min(1.0, cos_t2))   # clamp for numerical safety

    sign = 1 if elbow_up else -1
    sin_t2 = sign * math.sqrt(1 - cos_t2**2)
    theta2 = math.atan2(sin_t2, cos_t2)

    #skulder
    theta1 = math.atan2(yw, xw) - math.atan2(L2 * sin_t2, L1 + L2 * cos_t2)

    #wrist
    theta3 = phi - theta1 - theta2

    #offsets: world-space angles -> servo degrees
    return (
        math.degrees(theta_base),
        math.degrees(theta1) - MOUNT_SKULDER,
        math.degrees(theta2) - MOUNT_ALBUE,
        math.degrees(theta3) - MOUNT_WRIST,
    )

#PID verdier
kp = 0.5
ki = 0.1
kd = 0.00

integral = 0
prev_error = 0
prev_time = time.time()

def pid_control(setpoint, measurement, integral, prev_error, prev_time):
    error = setpoint - measurement
    current_time = time.time()
    dt = current_time - prev_time

    if dt <= 0:
        return 0, integral, error, current_time

    integral += error * dt
    derivative = (error - prev_error) / dt

    output = kp * error + ki * integral + kd * derivative

    return output, integral, error, current_time

#GUI
root = Tk()
root.title("Arm Controller")
root.geometry("800x800")

#main window
canvas  = Canvas(root)
vscroll = Scrollbar(root, orient=VERTICAL, command=canvas.yview)
canvas.configure(yscrollcommand=vscroll.set)
vscroll.pack(side=RIGHT, fill=Y)
canvas.pack(side=LEFT, fill=BOTH, expand=True)
main = Frame(canvas)
canvas_window = canvas.create_window((0, 0), window=main, anchor="nw")

def on_frame_configure():
    canvas.configure(scrollregion=canvas.bbox("all"))
def on_canvas_configure(e):
    canvas.itemconfig(canvas_window, width=e.width)
main.bind("<Configure>", on_frame_configure)
canvas.bind("<Configure>", on_canvas_configure)
def _on_mousewheel(e):
    if e.num == 4:
        canvas.yview_scroll(-1, "units")
    elif e.num == 5:
        canvas.yview_scroll(1, "units")
    elif e.delta:
        canvas.yview_scroll(-1 * (e.delta // 120), "units")

root.bind_all("<MouseWheel>", _on_mousewheel)
root.bind_all("<Button-4>", _on_mousewheel)
root.bind_all("<Button-5>", _on_mousewheel)
midje_var   = DoubleVar(value=0)
skulder_var = DoubleVar(value=0)
albue_var   = DoubleVar(value=0)
wrist_var   = DoubleVar(value=0)
pump_var    = DoubleVar(value=0)

JOINT_VARS = [midje_var, skulder_var, albue_var, wrist_var, pump_var]

def get_joints():
    return [v.get() for v in JOINT_VARS]

def set_joints(values):
    for var, val in zip(JOINT_VARS, values):
        var.set(val)
    drive(*values)

Label(main, text=" Joint Control ", font=("Segoe UI", 11, "bold")).pack(pady=(10, 2))

def make_slider(label, var, from_, to):
    f = Frame(main)
    f.pack(fill="x", padx=20, pady=1)
    Label(f, text=label, width=8, anchor="w").pack(side=LEFT)
    s = Scale(f, variable=var, from_=from_, to=to, orient=HORIZONTAL,
              length=380, resolution=1)
    s.pack(side=LEFT, fill="x", expand=True)
    s.config(command=lambda _: drive(*get_joints()))

make_slider("Midje",   midje_var,  45, -45)
make_slider("Skulder", skulder_var, 45, -45)
make_slider("Albue",   albue_var,   45, -45)
make_slider("Wrist",   wrist_var,   45, -45)

def on_pump_slider(_):
    pct = int(pump_var.get())
    if pct == 0:
        pump_fwd.off()
    else:
        pump_fwd.on()
    drive(*get_joints())

f_pump = Frame(main)
f_pump.pack(fill="x", padx=20, pady=1)
Label(f_pump, text="Pump", width=8, anchor="w").pack(side=LEFT)
pump_scale = Scale(f_pump, variable=pump_var, from_=0, to=100,
                   orient=HORIZONTAL, length=380, resolution=1,
                   command=on_pump_slider)
pump_scale.pack(side=LEFT, fill="x", expand=True)

def reset_all():
    set_joints([0, 0, 0, 0, 0])

Button(main, text="Reset", command=reset_all).pack(pady=4)

def toggle_activate():
    global activate
    activate = not activate
    activate_btn.config(
        text="Deactivate" if activate else "Activate Main Program",
        bg="red" if activate else activate_btn_default_bg
    )

activate_btn = Button(main, text="Activate Main Program", command=toggle_activate,
                      font=("Segoe UI", 10, "bold"), width=24)
activate_btn.pack(pady=6)
activate_btn_default_bg = activate_btn.cget("bg")

#IK input 
Label(main, text=" Inverse Kinematics ", font=("Segoe UI", 11, "bold")).pack(pady=(14, 2))

ik_frame = Frame(root)
ik_frame.pack(padx=20, fill="x")

def entry_row(parent, label, default):
    f = Frame(parent)
    f.pack(fill="x", pady=1)
    Label(f, text=label, width=12, anchor="w").pack(side=LEFT)
    var = DoubleVar(value=default)
    Entry(f, textvariable=var, width=8).pack(side=LEFT)
    return var

ik_x              = entry_row(ik_frame, "X (cm)",          15.0)
ik_y              = entry_row(ik_frame, "Y (cm)",           0.0)
ik_z              = entry_row(ik_frame, "Z (cm)",          10.0)
ik_phi            = entry_row(ik_frame, "φ orient°",        0.0)
ik_zbase          = entry_row(ik_frame, "Base ht (cm)",   Z_BASE)
ik_mount_skulder  = entry_row(ik_frame, "Skulder mount°", MOUNT_SKULDER)

ik_status = Label(main, text="", fg="red")
ik_status.pack()

def run_ik():
    try:
        global Z_BASE, MOUNT_SKULDER
        Z_BASE        = ik_zbase.get()
        MOUNT_SKULDER = ik_mount_skulder.get()
        base, t1, t2, t3 = solve_ik(
            ik_x.get(), ik_y.get(), ik_z.get(), ik_phi.get()
        )
        target = [base, t1, t2, t3, pump_var.get()]
        global move_start, move_target
        move_start  = get_joints()
        move_target = target
        smooth_step(0)
        ik_status.config(text=f"M:{base:+.1f}°  S:{t1:+.1f}°  A:{t2:+.1f}°  W:{t3:+.1f}°", fg="green")
    except Exception as e:
        ik_status.config(text=str(e), fg="red")

#kontrollere hastigheten
move_start  = [0.0] * 5
move_target = [0.0] * 5
MOVE_STEPS   = 40
MOVE_MS      = 15   # ms/step

f_speed = Frame(main)
f_speed.pack(fill="x", padx=20, pady=(4, 0))
Label(f_speed, text="Speed", width=8, anchor="w").pack(side=LEFT)
speed_var = IntVar(value=MOVE_MS)
Label(f_speed, text="Fast", width=4).pack(side=LEFT)
Scale(f_speed, variable=speed_var, from_=5, to=80,
      orient=HORIZONTAL, length=300, resolution=5,
      command=lambda v: set_speed(int(v))
      ).pack(side=LEFT)

def set_speed(v):
    global MOVE_MS
    MOVE_MS = v
Label(f_speed, text="Slow").pack(side=LEFT)

#positions
Label(main, text=" Saved Positions ", font=("Segoe UI", 11, "bold")).pack(pady=(14, 2))

NUM_POS = 3
saved   = [None] * NUM_POS

def smooth_step(step):
    t = step / MOVE_STEPS
    t = t * t * (3 - 2 * t)
    interp = [move_start[i] + (move_target[i] - move_start[i]) * t for i in range(5)]
    set_joints(interp)
    if step < MOVE_STEPS:
        root.after(MOVE_MS, lambda: smooth_step(step + 1))

def go_to(idx):
    if saved[idx] is None:
        return
    global move_start, move_target
    move_start  = get_joints()
    move_target = list(saved[idx])
    smooth_step(0)

def save_pos(idx):
    saved[idx] = get_joints()
    m, s, a, w, p = saved[idx]
    pos_labels[idx].config(
        text=f"M:{m:+.0f}°  S:{s:+.0f}°  A:{a:+.0f}°  W:{w:+.0f}°  P:{p:.0f}%"
    )
    go_btns[idx].config(state=NORMAL)

pos_labels = []
go_btns    = []

for i in range(NUM_POS):
    f = Frame(main, relief="groove", bd=1)
    f.pack(fill="x", padx=20, pady=3)
    Label(f, text=f"Position {i+1}", font=("Segoe UI", 9, "bold"), width=10).pack(side=LEFT, padx=4)
    lbl = Label(f, text="(empty)", anchor="w", width=32)
    lbl.pack(side=LEFT)
    pos_labels.append(lbl)
    Button(f, text="Save", width=5, command=lambda i=i: save_pos(i)).pack(side=LEFT, padx=2)
    go = Button(f, text="Go", width=4, state=DISABLED, command=lambda i=i: go_to(i))
    go.pack(side=LEFT, padx=2)
    go_btns.append(go)

#load cells
Label(main, text=" Load Cell ", font=("Segoe UI", 11, "bold")).pack(pady=(14, 2))

use_median = False

for lbl_text, lbl_var in [("Sensor 1", None), ("Sensor 2", None), ("Sensor 3", None)]:
    Label(main, text=lbl_text, font=("Segoe UI", 9)).pack()

weight_lbl1 = Label(main, text="-- g", font=("Segoe UI", 24, "bold"))
weight_lbl2 = Label(main, text="-- g", font=("Segoe UI", 24, "bold"))
weight_lbl3 = Label(main, text="-- g", font=("Segoe UI", 24, "bold"))
weight_lbl1.pack()
weight_lbl2.pack()
weight_lbl3.pack()

mode_btn = Button(main, text="Mode: Live", width=16)
mode_btn.pack(pady=4)

def toggle_mode():
    global use_median
    use_median = not use_median
    mode_btn.config(text="Mode: Median" if use_median else "Mode: Live")

mode_btn.config(command=toggle_mode)

def read(sensor):
    if use_median:
        return (sensor.read_median() - sensor.hx_offset) / sensor.scale_factor
    return sensor.read_grams()

def poll_hx711():
    interval = 500 if use_median else 200
    for sensor, lbl in [(hx711.sensor1, weight_lbl1),
                        (hx711.sensor2, weight_lbl2),
                        (hx711.sensor3, weight_lbl3)]:
        try:
            lbl.config(text=f"{read(sensor):.1f} g")
        except Exception:
            lbl.config(text="err")
    root.after(interval, poll_hx711)

sensors = [hx711.sensor1, hx711.sensor2, hx711.sensor3]

def open_calibration():
    win = Toplevel(root)
    win.title("Load Cell Calibration")
    win.resizable(False, False)

    for i, sensor in enumerate(sensors):
        frame = LabelFrame(win, text=f"Sensor {i+1}", padx=10, pady=6)
        frame.pack(fill="x", padx=12, pady=6)

        reading_lbl = Label(frame, text="-- g", font=("Segoe UI", 13, "bold"), width=10)
        reading_lbl.pack(side=RIGHT)

        def refresh(lbl=reading_lbl, s=sensor):
            try:
                lbl.config(text=f"{s.read_grams():.1f} g")
            except Exception:
                lbl.config(text="err")
            win.after(300, lambda: refresh(lbl, s))

        refresh()

        Button(frame, text="Tare", width=8,
               command=lambda s=sensor: s.tare()).pack(side=LEFT, padx=4)

        cal_entry = Entry(frame, width=7)
        cal_entry.insert(0, "200")
        cal_entry.pack(side=LEFT, padx=4)
        Label(frame, text="g").pack(side=LEFT)

        status_lbl = Label(frame, text="", fg="green", width=10)
        status_lbl.pack(side=LEFT, padx=4)

        def do_cal(s=sensor, e=cal_entry, lbl=status_lbl):
            try:
                s.calibrate(float(e.get()))
                lbl.config(text="OK")
            except Exception as ex:
                lbl.config(text=str(ex), fg="red")

        Button(frame, text="Calibrate", width=9, command=do_cal).pack(side=LEFT, padx=2)

Button(main, text="Tare & Calibrate", command=open_calibration).pack(pady=4)

# physical button tareing
TARE_BUTTON_PINS = {
    1: 2,   # GPIO1 tares sensor 3 (sensors[2])
    7: 1,   # GPIO7 tares sensor 2 (sensors[1])
    8: 0,   # GPIO8 tares sensor 1 (sensors[0])
}

def make_tare_handler(idx):
    def handler():
        try:
            sensors[idx].tare()
        except IndexError:
            print(f"[GPIO] No sensor at index {idx}")
        except Exception as e:
            print(f"[GPIO] Tare failed for sensor {idx + 1}: {e}")
    return handler

tare_buttons = [] #keep ref to buttons
for pin, sensor_idx in TARE_BUTTON_PINS.items():
    if sensor_idx < len(sensors):
        btn = GPIOButton(pin, pull_up=True)
        btn.when_pressed = make_tare_handler(sensor_idx)
        tare_buttons.append(btn)

FILL_THRESHOLD_G = 150   # start filling if glass is below threshhold
FILL_TARGET_G    = 400   # stop filling when glass reaches threshhold
PID_POLL_MS      = 200   # sensor read interval (ms)

_fill_sensor_idx = 0

#fill innstillinger
Label(main, text=" Fill Settings ", font=("Segoe UI", 11, "bold")).pack(pady=(14, 2))
_fill_frame = Frame(main)
_fill_frame.pack(padx=20, fill="x")

def fill_row(parent, label, default):
    f = Frame(parent)
    f.pack(fill="x", pady=1)
    Label(f, text=label, width=16, anchor="w").pack(side=LEFT)
    var = DoubleVar(value=default)
    Entry(f, textvariable=var, width=8).pack(side=LEFT)
    Label(f, text="g").pack(side=LEFT)
    return var

threshold_var = fill_row(_fill_frame, "Start below (g)",  FILL_THRESHOLD_G)
target_var    = fill_row(_fill_frame, "Fill target (g)",  FILL_TARGET_G)

fill_status = Label(main, text="", fg="gray")
fill_status.pack()

def apply_fill_settings():
    global FILL_THRESHOLD_G, FILL_TARGET_G
    FILL_THRESHOLD_G = threshold_var.get()
    FILL_TARGET_G    = target_var.get()
    fill_status.config(text=f"Threshold={FILL_THRESHOLD_G:.0f}g  Target={FILL_TARGET_G:.0f}g", fg="green")

Button(main, text="Apply Fill Settings", command=apply_fill_settings).pack(pady=4)

def start_fill(idx):
    global fill_state, fill_sensor_idx
    fill_state      = "moving"
    fill_sensor_idx = idx
    go_to(idx)
    root.after(MOVE_STEPS * MOVE_MS + 500, begin_pump)

def begin_pump():
    global fill_state, integral, prev_error, prev_time
    fill_state = "filling"
    pump_fwd.on()
    integral   = 0
    prev_error = 0
    prev_time  = time.time()
    fill_status.config(text="Filling...", fg="blue")
    pid_fill_loop()

def pid_fill_loop():
    global integral, prev_error, prev_time
    if fill_state != "filling":
        return
    try:
        sensors = [hx711.sensor1, hx711.sensor2, hx711.sensor3]
        grams   = sensors[_fill_sensor_idx].read_grams()

        if grams < 0:
            stop_pump()
            fill_status.config(text="Glass lifted — fill cancelled", fg="orange")
            return

        if grams >= FILL_TARGET_G:
            stop_pump()
            return

        output, integral, prev_error, prev_time = pid_control(
            FILL_TARGET_G, grams, integral, prev_error, prev_time
        )
        power = max(5, min(100, int(output)))
        pump_fwd.on()
        desired_duty = int(power / 100 * 65535)
        kit._pca.channels[4].duty_cycle = 65535 - desired_duty
        pump_var.set(power)
        fill_status.config(text=f"Filling: {grams:.0f} / {FILL_TARGET_G:.0f} g  |  pump {power}%", fg="blue")

    except Exception as ex:
        fill_status.config(text=f"Sensor error: {ex}", fg="red")

    root.after(PID_POLL_MS, pid_fill_loop)

def stop_pump():
    global fill_state
    kit._pca.channels[4].duty_cycle = 0
    pump_fwd.off()
    pump_var.set(0)
    fill_state = "idle"
    fill_status.config(text=f"Done — {FILL_TARGET_G:.0f} g reached", fg="green")
    root.after(1000, main_loop)

def main_loop():
    if not activate or fill_state != "idle":
        root.after(500, main_loop)
        return
    sensors = [hx711.sensor1, hx711.sensor2, hx711.sensor3]
    for idx, sensor in enumerate(sensors):
        try:
            grams = sensor.read_grams()
            if grams < 0:
                continue   #løftet glass
            if grams < FILL_THRESHOLD_G:
                start_fill(idx) #fyll glass
                return
        except Exception:
            pass
    root.after(500, main_loop)


#water level
GLASS_MAX_G = 500

Label(main, text=" Water Level ", font=("Segoe UI", 11, "bold")).pack(pady=(10, 2))

bar_vars  = []
bar_grams = []

for name in ["Glass 1", "Glass 2", "Glass 3"]:
    f = Frame(root)
    f.pack(fill="x", padx=20, pady=3)
    Label(f, text=name, width=8, anchor="w").pack(side=LEFT)
    var = IntVar(value=0)
    bar = ttk.Progressbar(f, variable=var, maximum=GLASS_MAX_G, length=300)
    bar.pack(side=LEFT, fill="x", expand=True, padx=4)
    g_lbl = Label(f, text="-- g", width=8, anchor="e")
    g_lbl.pack(side=LEFT)
    bar_vars.append(var)
    bar_grams.append(g_lbl)

def update_bars():
    for var, lbl, sensor in zip(bar_vars, bar_grams,
                                [hx711.sensor1, hx711.sensor2, hx711.sensor3]):
        try:
            g = sensor.read_grams()
            var.set(max(0, min(GLASS_MAX_G, int(g))))
            lbl.config(text=f"{g:.0f} g")
        except Exception:
            lbl.config(text="err")
    root.after(300, update_bars)

#PID verdier
Label(main, text=" PID Controller ", font=("Segoe UI", 11, "bold")).pack(pady=(14, 2))

pid_frame = Frame(main)
pid_frame.pack(padx=20, fill="x")

def pid_row(parent, label, default):
    f = Frame(parent)
    f.pack(fill="x", pady=1)
    Label(f, text=label, width=6, anchor="w").pack(side=LEFT)
    var = DoubleVar(value=default)
    Entry(f, textvariable=var, width=8).pack(side=LEFT)
    return var

pid_kp_var = pid_row(pid_frame, "Kp", kp)
pid_ki_var = pid_row(pid_frame, "Ki", ki)
pid_kd_var = pid_row(pid_frame, "Kd", kd)

pid_status = Label(main, text=f"Active: Kp={kp}  Ki={ki}  Kd={kd}", fg="gray")
pid_status.pack()

def apply_pid():
    global kp, ki, kd, integral, prev_error, prev_time
    kp = pid_kp_var.get()
    ki = pid_ki_var.get()
    kd = pid_kd_var.get()
    integral   = 0
    prev_error = 0
    prev_time  = time.time()
    pid_status.config(text=f"Active: Kp={kp}  Ki={ki}  Kd={kd}", fg="green")

Button(main, text="Apply PID", command=apply_pid).pack(pady=4)

#start
reset_all()
poll_hx711()
update_bars()
main_loop()
root.mainloop()

hx711.sensor1.close()
hx711.sensor2.close()
hx711.sensor3.close()
hx711.sck.close()
pump_fwd.close()

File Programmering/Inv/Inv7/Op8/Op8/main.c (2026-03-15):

/*
 * 38400 baud
 *
 *   "ADC\n"     
 *   "TMP\n"       
 *   "LED:n\n"     
 *   "SERVO:X\n"     
 *   "BUZZ:X\n"      
 *   "BUZZ:0\n"        
 */

#define F_CPU 16000000UL
#include <avr/io.h>
#include <avr/cpufunc.h>
#include <avr/interrupt.h>
#include <util/delay.h>
#include <stdio.h>
#include <string.h>
#include <stdlib.h>

#include "usart.h"
#include "adc.h"
#include "analog.h"
#include "buzzer.h"
#include "pwm.h"

static void xosc_16MHz_init(void){
    ccp_write_io((void*)&CLKCTRL.XOSCHFCTRLA,
        CLKCTRL_RUNSTBY_bm |
        CLKCTRL_FRQRANGE_16M_gc |
        CLKCTRL_SELHF_XTAL_gc |
        CLKCTRL_CSUTHF_4K_gc |
        CLKCTRL_ENABLE_bm);
    while(!(CLKCTRL.MCLKSTATUS & CLKCTRL_EXTS_bm));
    ccp_write_io((void*)&CLKCTRL.MCLKCTRLA, CLKCTRL_CLKSEL_EXTCLK_gc);
    while(CLKCTRL.MCLKSTATUS & CLKCTRL_SOSC_bm);
}

//LED
#define LED_MASK (PIN0_bm | PIN1_bm | PIN2_bm | PIN3_bm)

static void led_init(void){
    PORTC.DIRSET = LED_MASK;
    PORTC.OUTSET = LED_MASK;
}
static void led_toggle(uint8_t n){
    uint8_t pin = (1 << (n & 0x03));
    PORTC.OUTTGL = pin;
}

//Servo
static uint16_t angle_to_ticks(uint8_t deg){
    if(deg > 180) deg = 180;
    return (uint16_t)(1000u + ((uint32_t)deg * 4000u) / 180u);
}

//USART2 (RPi)
static uint8_t usart2_getline(char *buf, uint8_t maxlen){
    uint8_t i = 0;
    while(i < maxlen - 1){
        while(!(USART2.STATUS & USART_RXCIF_bm)){}
        char c = USART2.RXDATAL;
        if(c == '\n' || c == '\r'){
            break;
        }
        buf[i++] = c;
    }
    buf[i] = '\0';
    return i;
}

static void usart2_puts(const char *s){
    while(*s){
        while(!(USART2.STATUS & USART_DREIF_bm)){}
        USART2.TXDATAL = *s++;
    }
}

//Main
int main(void){
    xosc_16MHz_init();
    usart_init();
    led_init();
    buzzer_init();
    pwm_1_servo_init();
    sei();

    //Printf goes to PC terminal
    stdout = &usart3_stdout;
    printf("IO-kort ready\r\n");

    char cmd[32];

    for(;;){
        // Wait for command
        usart2_getline(cmd, sizeof(cmd));
        printf("CMD: %s\r\n", cmd);   //Echo command

        if(strcmp(cmd, "ADC") == 0){
            adc0_init_pot_ain4_vdd_freerun();
            uint16_t raw = adc0_read12_wait();
            char reply[16];
            snprintf(reply, sizeof(reply), "ADC:%u\n", raw);
            usart2_puts(reply);
            printf("ADC: %u\r\n", raw);

        } else if(strcmp(cmd, "TMP") == 0){
            adc0_init_tmp_freerun();
            uint16_t raw = adc0_read12_wait();
            uint16_t mv  = adc_to_mV_2048(raw);
            int16_t  deg = tmp235_C_from_mV(mv);
            char reply[16];
            snprintf(reply, sizeof(reply), "TMP:%d\n", deg);
            usart2_puts(reply);
            printf("TMP: %d C\r\n", deg);

        } else if(strncmp(cmd, "LED:", 4) == 0){
            uint8_t n = (uint8_t)atoi(cmd + 4);
            led_toggle(n);
            usart2_puts("OK\n");
            printf("LED%d toggled\r\n", n);

        } else if(strncmp(cmd, "SERVO:", 6) == 0){
            uint8_t deg = (uint8_t)atoi(cmd + 6);
            pwm_1_servo_set_pos(angle_to_ticks(deg));
            usart2_puts("OK\n");
            printf("SERVO: %d deg\r\n", deg);

        } else if(strncmp(cmd, "BUZZ:", 5) == 0){
            uint16_t freq = (uint16_t)atoi(cmd + 5);
            if(freq == 0){
                buzzer_stop();
            } else {
                buzzer_beep(freq, 200);
            }
            usart2_puts("OK\n");
            printf("BUZZ: %u Hz\r\n", freq);

        } else {
            usart2_puts("ERR\n");
            printf("Unknown: %s\r\n", cmd);
        }
    }
}

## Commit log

2026-02-02 Udate: nyttige lenker og schematic
2026-02-02 Update: I2C
2026-02-04 DC_MOTOR pumpe greier
    [AUT2606_Semester_Prosjekt.PrjPcb, MX1508.SchDoc, RasberryPi5.SchDoc]
2026-02-09 STL filer og assembly
    [Arm 01.STL, Arm 02 v3.STL, Arm 03.STL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]
2026-02-10 Update: PcA
    [RasberryPi5.SchDoc]
2026-02-11 fikse hx711 og pwm input
    [HX711.SchDoc, RasberryPi5.SchDoc]
2026-02-12 Noka e gæli
    [HX711_1.SchDoc, HX711_2.SchDoc, HX711_3.SchDoc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]
2026-02-12 PCB - fjernet knapper
    [PCB1.PcbDoc, RasberryPi5.SchDoc]
2026-02-12 bibliotek greier
    [AUT2606_Semester_Prosjekt.PrjPcb, PCB1.PcbDoc, Sheet1.SchDoc]
2026-02-12 HX711 output fix
    [Main.SchDoc, RasberryPi5.SchDoc]
2026-02-12 Update: PCb
    [HX711.PcbDoc, HX711_1.SchDoc, HX711_2.SchDoc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]
2026-02-12 Ferdig med hx711
    [HX711.PcbDoc, HX711_1.SchDoc, HX711_2.SchDoc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]
2026-02-12 Update: Net label
    [Main.PcbDoc, RasberryPi5.SchDoc]
2026-02-13 skifte transistorer, motstander, fant en header, osv.
    [HX711_1.SchDoc, HX711_2.SchDoc, HX711_3.SchDoc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]
2026-02-13 rearange pcb
    [HX711.PcbDoc, HX711_1.SchDoc, HX711_2.SchDoc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]
2026-02-13 pcb greier
    [Main.PcbDoc, RasberryPi5.SchDoc]
2026-02-13 nesten ferdig
    [HX711.PcbDoc, Main.PcbDoc, RasberryPi5.SchDoc]
2026-02-14 ferdig for idag
    [RasberryPi5.SchDoc]
2026-02-14 Update: Ferdi main pcb
    [Main.PcbDoc]
2026-02-14 fixed header
    [AUT2606_Semester_Prosjekt.PrjPcb, HX711.PcbDoc, Main.PcbDoc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]
2026-02-14 silktrykk og små endringer
    [HX711.PcbDoc, HX711_1.SchDoc, HX711_2.SchDoc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]
2026-02-14 mer silktrykk
    [HX711.PcbDoc, Main.PcbDoc]
2026-02-14 skiftet navn
    [Main.PcbDoc, RobotArm_HX711_Olav_Nikolai.PcbDoc, RobotArm_Olav_Nikolai.PcbDoc]
2026-02-14 Readme and Draftsman-dokument
    [AUT2606_Semester_Prosjekt.PrjPcb, RasberryPi5.SchDoc, RobotArm_HX711_Olav_Nikolai.PcbDoc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]
2026-02-16 PCB PDF
    [AUT2606_Semester_Prosjekt.PrjPcb]
2026-02-16 servo funke nu
2026-02-18 fix buttons
    [RasberryPi5.SchDoc, RobotArm_HX711_Olav_Nikolai.PcbDoc, RobotArm_Olav_Nikolai.PcbDoc]
2026-02-20 I2C og SDA
    [RasberryPi5.SchDoc, RobotArm_Olav_Nikolai.PcbDoc]
2026-03-09 fix i2c header
    [HX711_1.SchDoc, HX711_2.SchDoc, HX711_3.SchDoc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]
2026-03-09 replace i2c header and pi header
    [RasberryPi5.SchDoc, RobotArm_Olav_Nikolai.PcbDoc]
2026-03-09 Update uart comnication
2026-03-16 arm forlengelse og servo fiks
    [Arm_01_10cm.STL, Arm_02_fiks.STL, Arm_02_fiks_10cm.STL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]
2026-03-19 Led update gui
2026-03-19 Litta update på servo here.
2026-03-19 Ekstra update servo
2026-03-22 de-AIed koden
2026-04-23 stl filer
    [Arm_01_10cm_woHole.STL, SammenSettArm2.stl, SammenSettArm2_woHole.stl]
2026-04-23 draftsmen endringer
    [AUT2606_Semester_Prosjekt.PrjPcb]
2026-05-04 PWM inv kanskje
2026-05-05 INV pwm nu
2026-05-06 INV pwm servo
2026-05-06 dimensjoner til PCB
    [AUT2606_Semester_Prosjekt.PrjPcb, HX711_1.SchDoc]
2026-05-06 tune pwm
2026-05-06 fiks pumpe
2026-05-07 kortere armer
    [Arm_01_5cm+ORG_woHole.gcode.3mf, Arm_01_5cm_woHole.STL]
2026-05-07 button test
2026-05-07 button in main
2026-05-07 PID verdi fix
2026-05-23 BOM excel
    [BOM.xlsx]
